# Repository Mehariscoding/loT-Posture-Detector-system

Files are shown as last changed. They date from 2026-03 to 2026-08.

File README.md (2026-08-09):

# IoT Posture Detector System

A closed-loop wearable posture monitoring and correction system designed for long-duration occupational use. The system uses dual IMU sensors to track spinal alignment in real time, delivers haptic feedback to correct slouching behaviour, logs session data to an SD card, and streams live metrics to a web-based dashboard over Bluetooth.

Built and tested as part of an ongoing research effort targeting occupational driver ergonomics.

---

## Repository Structure

```
README.md
CHANGELOG.md
V1/
├── Software/        # Arduino firmware and web dashboard
├── Hardware/        # STL files and wiring schematics
├── Data/            # Session logs and science fair dataset
└── Presentables/    # Judge summary and presentation materials
V2/
├── posture_detector_v2.ino        # ESP32 firmware
├── posture_dashboard_v2_ml.html   # ML dashboard
└── posture_session_v2_ml.csv      # 122-minute stability test data
```

---

## System Overview

Two MPU-6050 IMU sensors are mounted at the upper and lower back. On startup the device runs a stability-based auto-calibration routine that collects 200 samples, identifies the most stable 50-sample window, removes outliers, and computes a median baseline, ensuring the reference posture is not corrupted by movement during initialization.

During monitoring, live sensor readings are continuously compared against the calibrated baseline. If either sensor detects more than 15 degrees of deviation for over 2.5 seconds, the vibration motor triggers a haptic correction alert. Every reading is logged to CSV on an SD card and simultaneously streamed over Bluetooth to a live web dashboard.

---

## V1 Hardware

| Part | Quantity |
|---|---|
| Arduino Uno | 1 |
| MPU-6050 IMU sensor | 2 |
| HC-10 Bluetooth module | 1 |
| Micro SD card module | 1 |
| Coin vibration motor | 1 |
| LED | 1 |
| NPN transistor (2N2222) | 1 |
| 1000uF 50V capacitor | 1 |
| 9V battery + holder | 1 |
| Resistors, jumper wires, breadboard | -- |

---

## V2 Hardware

| Part | Quantity |
|---|---|
| ESP32 Huzzah 32 | 1 |
| MPU-6050 IMU sensor | 2 |
| Micro SD card module | 1 |
| LiPo battery 3000mAh 3.7V | 1 |
| TP4056 charging module | 1 |
| MT3608 boost converter | 1 |
| Coin vibration motor | 1 |
| LED | 1 |
| NPN transistor (2N2222) | 1 |
| Slide switch | 1 |
| JST connectors | 3 |
| Resistors, jumper wires, breadboard | -- |

---

## V1 Wiring

| Component | Arduino Pin |
|---|---|
| MPU-6050 upper (0x68) SDA | A4 |
| MPU-6050 upper (0x68) SCL | A5 |
| MPU-6050 lower (0x69) SDA | A4 (shared) |
| MPU-6050 lower (0x69) SCL | A5 (shared) |
| MPU-6050 lower AD0 | 3.3V |
| HC-10 TXD | Pin 8 |
| HC-10 RXD | Pin 9 |
| SD card CS | Pin 5 |
| LED | Pin 7 |
| Motor (via transistor) | Pin 6 |
| Battery positive | VIN |
| Battery negative | GND |

---

## V2 Wiring

| Component | ESP32 Pin |
|---|---|
| MPU-6050 upper (0x68) SDA | GPIO 23 |
| MPU-6050 upper (0x68) SCL | GPIO 22 |
| MPU-6050 lower (0x69) SDA | GPIO 23 (shared) |
| MPU-6050 lower (0x69) SCL | GPIO 22 (shared) |
| MPU-6050 lower AD0 | 3.3V |
| SD card MOSI | GPIO 18 |
| SD card MISO | GPIO 19 |
| SD card SCK | GPIO 5 |
| SD card CS | GPIO 21 |
| LED | GPIO 12 |
| Motor (via transistor) | GPIO 14 |
| LiPo positive | TP4056 BAT+ |
| TP4056 OUT+ | MT3608 IN+ |
| MT3608 OUT+ | ESP32 VIN |

---

## Libraries

**V1:**
- MPU6050 by Electronic Cats
- SD (built in)
- SoftwareSerial (built in)
- Wire (built in)

**V2:**
- MPU6050 by Electronic Cats
- SD (built in)
- Wire (built in)
- BLEDevice (built in ESP32 core)

---

## Setup

**V1:**
1. Open V1/Software/Posture_Detector.ino in Arduino IDE
2. Install required libraries
3. Select Arduino Uno under Tools, Board
4. Select correct port under Tools, Port
5. Click Upload

**V2:**
1. Open V2/posture_detector_v2.ino in Arduino IDE
2. Install ESP32 board package by Espressif Systems
3. Select Adafruit ESP32 Feather under Tools, Board
4. Select correct port under Tools, Port
5. Click Upload

---

## Usage

1. Power on the device
2. Sit or stand in your natural upright posture
3. Hold still, calibration runs automatically and confirms with a buzz
4. Device monitors continuously and vibrates to correct slouching

---

## Dashboard

**V1:** Open V1/Software/posture_dashboard.html in Chrome.
1. Click Connect to HC-10
2. Select device from Bluetooth scan list
3. Live pitch, roll, status, and score stream in real time

**V2:** Open V2/posture_dashboard_v2_ml.html in Chrome.
1. Click Connect
2. Select PostureDetector_V2 from Bluetooth scan list
3. Live ML inference streams in real time
4. Multi-class classifier, predictive deterioration model, and anomaly detection run in browser

---

## Data Format

SD card logs to posture.csv:

```
Time(ms), PitchU, RollU, PitchL, RollL, Status, Score(%)
```

BLE stream format:

```
U:0.3/0.0 L:0.2/0.1 GOOD 100%
```

---

## 3D Printed Enclosure

**V1:** STL files in V1/Hardware/. Printed in PLA on a Bambu Lab P1S.
- Main case: 150mm x 100mm x 40mm
- Sensor case: 40mm x 45mm x 20mm
- Fastened with M3 thumb screws

**V2:** Redesigned dual elastic band system with TPU cable sleeve. PCB enclosure in development.

---

## Known Limitations (V1)

- Bluetooth connection drops after approximately 20-30 minutes due to power instability on the HC-10 module
- 9V battery provides inconsistent voltage under motor load
- Single-snapshot calibration vulnerable to initialization error if user moves during startup

All of these are resolved in V2.

---

## Stability Test (V2)

- 13,874 readings over 122 continuous minutes
- Zero Bluetooth dropouts
- Max gap between readings: 660ms (expected: 500ms)
- Confirms ESP32 native BLE fully resolves V1 dropout issue

---

## Roadmap

| Version | Status | Key upgrades |
|---|---|---|
| V1 | Complete | Arduino, HC-10, breadboard prototype |
| V2 | Prototype Complete, PCB In Development | ESP32, native BLE, robust calibration, ML dashboard, LiPo power |

---

## Author

Mehar -- Grade 10, Peel Region, Ontario
[GitHub](https://github.com/Mehariscoding)

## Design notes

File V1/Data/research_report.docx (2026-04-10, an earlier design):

IoT Wearable Posture Correction System

Using Dual-Axis IMU Sensors and Real-Time Haptic Feedback

A Research Report Submitted to the Peel Region Science Fair 2025

Mehar

Grade 10, Intermediate Division

Peel Region, Ontario

April 2025

Abstract

Back pain is one of the most widespread health problems in Canada and poor seated posture is a major cause of it. This report presents the design, construction, and testing of a custom-built wearable IoT device that monitors spinal posture in real time using two MPU-6050 inertial measurement unit sensors and delivers vibration alerts when bad posture is detected. The main research question is whether real-time haptic feedback from the device actually causes posture to improve, or whether posture would improve on its own just from wearing the device over time.

Eight 30-minute sessions of data were collected. Sessions 1 through 4 were run with haptic feedback active and sessions 5 through 8 were run with the vibration motor disabled in firmware. Results showed that sessions with feedback averaged 86.3% good posture compared to just 5.3% without feedback. That is a 16-fold difference. The hypothesis was fully supported. The vibration feedback is the main cause of posture improvement, not habit or awareness from wearing the device alone.

Table of Contents

1. Introduction 4

2. Background and Literature Review 5

3. Hypothesis 6

4. Materials and Methods 6

5. Results 9

6. Discussion 11

7. Conclusion 13

8. Future Work 13

9. References 15

1. Introduction

Back pain is one of the most common health problems in Canada. A population-based study found that 83.8% of Canadians will experience back pain in their lifetime, and 34.2% experience it in any given week (Gross et al., 2006). The Canadian Chiropractic Association reports that nearly 45% of Canadians have activity limitations because of chronic back pain, and it is the second-leading driver of short and long-term disability claims in Canada in the occupational context (CCA, 2023). A significant driver of this problem is poor seated posture, especially for students and office workers who sit for several hours per day without any feedback about their spinal alignment.

Current solutions to poor posture are mostly passive. Ergonomic chairs and lumbar supports help but do not correct posture in real time. Commercial wearable devices like the Upright Go 2 exist but use a single sensor on the upper back and cost over $100 USD. No affordable device monitors both the upper and lower back independently and provides live data logging that researchers or clinicians can access. This project addresses that gap by designing and testing a custom-built dual-sensor wearable IoT device from scratch using an Arduino microcontroller, dual MPU-6050 IMU sensors, a vibration motor, and a Bluetooth Low Energy module connected to a real-time web dashboard.

The core research question is: does real-time haptic feedback from a wearable IoT device significantly improve seated posture quality, and is that feedback the actual cause of improvement rather than just wearing the device over time? To answer this, an experimental design was used with four sessions under each condition, with and without the vibration feedback enabled, keeping all other variables constant.

2. Background and Literature Review

2.1 The Problem With Seated Posture

When a person sits for extended periods, the natural tendency is to drift into a forward head position, rounded shoulders, and a flexed lumbar spine. This is sometimes called a slouch posture or C-curve posture. Over time this loading pattern increases stress on the intervertebral discs, compresses posterior spinal structures, and strains the muscles of the thoracic and lumbar regions. The result is chronic back pain that worsens the longer the habit goes uncorrected.

The spine has three natural curves that distribute body weight optimally: cervical lordosis at the neck, thoracic kyphosis at the upper back, and lumbar lordosis at the lower back. A neutral spine maintains all three curves simultaneously. Researchers using IMU sensors placed at thoracic and lumbar vertebral levels define neutral spine as the position where the head and upper trunk are aligned over the rest of the spine, typically captured during a brief upright standing or sitting trial before measurement begins (Carbonaro et al., 2021). This is the anatomical target this device attempts to monitor.

2.2 Haptic Feedback for Posture Correction

Haptic feedback, meaning vibration-based alerts delivered directly to the body, is the most effective and least disruptive method for real-time posture correction. It does not require the user to look at a screen and does not disturb other people nearby the way an auditory alert would. Research has confirmed this across multiple populations (Encyclopedia MDPI, 2024).

The most directly relevant published study is Ferrone et al. (2021), published in MDPI Sensors. The study tested a wearable haptic feedback device using dual IMU sensors on nurses performing common work tasks. The device was tested across three sessions: a baseline session with no feedback, a training session with feedback active, and a validation session with feedback removed. Results showed posture improvement of over 40% for pitch and roll axes comparing the baseline to the training session, and over 50% improvement comparing the baseline to the post-training validation session. Critically, the improvement persisted even after the feedback was removed in session three, suggesting that haptic feedback not only prompts correction in the moment but conditions longer-term postural behaviour. This study used the same sensor type and methodology as this project and directly motivated its design.

2.3 The Calibration Problem

One of the most important challenges in wearable posture devices is ensuring that calibration captures actual good posture rather than the user's habitual or bad posture. If the device calibrates while the user is already slouching, the entire 15-degree threshold is measured from that slouch, meaning the device could allow significant real-world deviation from neutral spine before triggering an alert. This is a known limitation in the field. Carbonaro et al. (2021) note that calibration in wearable IMU systems requires the user to hold a verified neutral anatomical position before data collection begins. Without this, the baseline is arbitrary.

In this study, the calibration limitation was partially addressed through verbal instruction before each session reminding the user to sit upright with ears over shoulders and shoulders over hips, and through consistent use of the same chair and desk across all sessions. However, neutral spine was not mechanically verified or confirmed with a reference tool. This is acknowledged as a limitation and future versions of the device will address it using a physiotherapist-verified standing calibration procedure and reference angle offsets based on published thoracic kyphosis norms.

2.4 Existing Commercial Devices

Several commercial posture wearables exist. The Upright Go 2 retails at approximately $100 USD, uses a single sensor on the upper back, delivers haptic feedback via an app, and stores data in the cloud through the app only with no offline logging. The Upright Go S is a cheaper single-sensor version at approximately $60 USD. The Lumo Lift, which is now discontinued, was a single-sensor device worn on the chest. None of these devices use dual sensors to monitor both the thoracic and lumbar spine independently, none provide offline SD card logging for research purposes, and none are open-source. This project addresses all three of those gaps.

3. Hypothesis

If a wearable IoT device delivers real-time vibration feedback when poor posture is detected, then the percentage of time spent in good posture will be significantly higher during sessions with feedback compared to sessions without feedback. This is because the vibration creates an immediate corrective signal that interrupts sustained bad posture, and repeated exposure to that signal across multiple sessions conditions faster correction responses over time.

4. Materials and Methods

4.1 Device Components

The following components were used to build the device:

- Arduino Uno R3 microcontroller (main processing unit)
- 2x MPU-6050 6-axis gyroscope and accelerometer IMU sensors (posture sensing)
- HC-10 Bluetooth Low Energy module (wireless data streaming to dashboard)
- Micro SD card module with 8GB SD card (offline session logging)
- Coin vibration motor, 3V (haptic alert output)
- NPN transistor 2N2222 with 1 kilohm resistor (motor switching circuit)
- Red LED with 220 ohm resistor (visual alert output)
- 1000 microfarad 50V electrolytic capacitor (power stabilization during motor activation spike)
- 9V battery with holder (portable power supply)
- 3D printed PLA enclosure, designed in Tinkercad, printed on Bambu Lab P1S
- Back brace for wearable mounting on the spine

4.2 Sensor Communication: I2C Protocol

Both MPU-6050 sensors communicate with the Arduino over the I2C bus using shared SDA and SCL lines. I2C allows multiple devices to share just two wires: the SDA line carries the data and the SCL line keeps timing in sync. Both MPU-6050 sensors default to I2C address 0x68, which would cause a bus conflict. To resolve this, the AD0 pin on the lower sensor was connected to 3.3V, which changes its address to 0x69. This allows the Arduino to communicate with the upper sensor at 0x68 and the lower sensor at 0x69 independently on the same two wires. The upper sensor was mounted at thoracic spine level between the shoulder blades. The lower sensor was mounted at lumbar spine level at the lower back.

4.3 Calibration Procedure

When the device is powered on, the user has 5 seconds to sit or stand in their best upright posture. During this period the Arduino samples both sensors 100 times at 10-millisecond intervals and calculates the average pitch and roll value at each sensor location. These averages are stored in memory as the personalized baseline for that session. From that point forward, any reading that deviates more than 15 degrees from the baseline at either sensor triggers the alert system.

The 15-degree threshold was chosen based on published research on IMU-based posture detection systems, which commonly use thresholds in the range of 10 to 20 degrees to balance sensitivity with false positive rate. A lower threshold would generate too many false alerts from normal movement. A higher threshold would miss moderate slouching.

4.4 Alert System Logic

The sensors sample posture at 500-millisecond intervals. When a reading exceeds the 15-degree threshold, a counter increments. The vibration motor and LED only activate after 5 consecutive bad readings, which equals 2.5 seconds of sustained bad posture. This delay prevents false alerts from brief intentional movements such as reaching for something. When the threshold is cleared, the counter resets immediately.

For sessions 5 through 8, the motor activation line was commented out in firmware before uploading to the Arduino. This means the LED still activated during bad posture events, providing a visual indicator, but the user could not feel the vibration. This was done to reduce conscious behavioural bias between conditions since most people are less likely to notice an LED indicator on their back than a vibration.

4.5 Web Dashboard

A real-time web dashboard was built in HTML and JavaScript using the Web Bluetooth API. It connects to the HC-10 BLE module through Chrome on a laptop, displays live pitch, roll, posture status, and a running session score, and allows the full session data to be exported as a CSV file. All session data used in this analysis was collected through this dashboard.

4.6 Experimental Design

Eight sessions were conducted over approximately one week. All sessions used the same desk, same chair, and the same activity: seated homework. Sessions lasted approximately 30 minutes each. Sessions 1 through 4 were conducted with haptic feedback fully active. Sessions 5 through 8 were conducted with the vibration motor disabled. The order was not randomized because the research question included whether posture naturally improves over time with repeated use, which required the feedback sessions to come first.

4.7 Variables

Independent variable: Presence or absence of haptic vibration feedback

Dependent variables: Percentage of readings classified as good posture, percentage classified as bad posture, number of discrete bad posture events per session

Controlled variables: Same desk, chair, activity, device placement on back brace, calibration procedure, session duration

Limitations: Single participant self-study, sensor placement may have varied slightly between sessions, calibration posture not mechanically verified as neutral spine, sessions were not randomized

4.8 Ethics

This project was conducted in compliance with Youth Science Canada's Participation of Humans in Research Low Risk policy. The participant is the student researcher. A Low Risk Approval Form was completed and signed by the participant and parent or guardian prior to data collection. An Informed Consent Letter and Permission Form were also signed. All data is identified only by session number with no additional personal identifiers. The research involves no physical risk beyond normal sitting and wearing of the device.

Claude (Anthropic, 2025) was used as an AI development assistant throughout this project, providing support with Arduino code debugging, BLE web dashboard development, and documentation. All hardware construction, physical assembly, soldering, wiring, sensor calibration, data collection, and analysis were performed independently by the student researcher, in accordance with Youth Science Canada's Guidelines for Using Generative AI in STEM Projects.

5. Results

5.1 Overview

Eight sessions totalling approximately 14,000 individual sensor readings were collected across roughly four hours of posture monitoring. Each session lasted between 17 and 36 minutes. The key metric used throughout this analysis is the percentage of readings classified as good posture, since the cumulative score resets on BLE reconnection and is therefore less reliable as a session-level metric.

5.2 Sessions With Haptic Feedback Active (Sessions 1 to 4)

Table 1 summarizes the four feedback sessions.

Table 1: Sessions with haptic feedback active

- Session 1 (29.4 min): Good posture 71.2%, Bad posture 12.7%, Bad events 40. Baseline session.
- Session 2 (33.1 min): Good posture 80.8%, Bad posture 6.0%, Bad events 39. Improvement of 9.6 percentage points from session 1.
- Session 3 (28.4 min): Good posture 96.0%, Bad posture 1.8%, Bad events 7. Strong conditioning effect observed.
- Session 4 (33.0 min): Good posture 97.1%, Bad posture 1.2%, Bad events 5. Peak performance across all sessions.
- Average: Good posture 86.3%, Bad posture 5.4%, Bad events 23 per session.

5.3 Sessions Without Haptic Feedback (Sessions 5 to 8)

Table 2 summarizes the four no-feedback sessions.

Table 2: Sessions without haptic feedback

- Session 5 (17.3 min): Good posture 13.2%, Bad posture 56.9%, Bad events 87. Immediate collapse without feedback.
- Session 6 (32.9 min): Good posture 1.0%, Bad posture 97.9%, Bad events 8. Sustained bad posture throughout entire session.
- Session 7 (30.3 min): Good posture 5.0%, Bad posture 82.8%, Bad events 82. Consistent with session 5 pattern.
- Session 8 (35.5 min): Good posture 2.0%, Bad posture 96.9%, Bad events 10. Sustained bad posture throughout.
- Average: Good posture 5.3%, Bad posture 83.6%, Bad events 47 per session.

5.4 Key Findings

The headline result is a 16-fold difference in average good posture percentage: 86.3% with feedback versus 5.3% without. Bad posture averaged 5.4% with feedback and 83.6% without. The number of discrete bad posture events per session averaged 23 with feedback and 47 without.

A clear progressive improvement was also observed across sessions 1 through 4. Good posture rose from 71.2% in session 1 to 97.1% in session 4. This represents an 87.5% reduction in bad posture events over the four feedback sessions, from 40 events in session 1 down to 5 in session 4.

Session 6 requires a specific note. It recorded only 8 bad posture events despite having 97.9% bad posture readings. This apparent contradiction is explained by the nature of the event counter. The counter increments only when a bad posture episode begins, not for each individual bad reading within an episode. When the participant stayed in bad posture continuously for an extended period rather than cycling in and out, the event count remained low while the percentage of bad readings remained very high. This is actually a stronger indicator of posture collapse than a high event count, because it means the participant was not making any correction attempts throughout most of the session.

6. Discussion

The results strongly support the hypothesis. Every session with haptic feedback produced dramatically higher good posture rates than every session without it. The 16-fold gap in average good posture percentage is large enough to be meaningful even given the limitations of a single-participant study.

The progressive improvement from 71.2% in session 1 to 97.1% in session 4 shows that the device does more than just prompt correction in the moment. It conditions faster and more automatic correction responses across repeated sessions. This is consistent with findings from Ferrone et al. (2021), who found posture improvements of over 50% persisted even after the feedback was removed in their post-training validation session. That post-training effect is analogous to what appears to happen across sessions 3 and 4 in this study, where good posture reached near-perfect levels even though the user was still in early sessions of use.

The no-feedback sessions are the most important part of the experimental design. Sessions 5 through 8 averaged 83.6% bad posture, which is worse than the very first session with feedback. This directly rules out the alternative explanation that posture naturally improves over time just from wearing the device or from general awareness of being monitored. Without the vibration signal, posture collapsed almost completely. The haptic feedback is not one contributing factor among several. It is the primary mechanism driving the result.

The calibration limitation is important to address honestly. If the user was already in a slightly slouched position during calibration, the 15-degree threshold would be measured from that slouch rather than from true neutral spine. This means the device could permit some real-world deviation from ideal posture before alerting. This is a genuine constraint of the current design and affects how confidently absolute posture quality can be claimed. However, it does not undermine the comparison between conditions, because the calibration procedure was identical in all eight sessions. Whatever offset existed was the same in both groups, so the 16-fold difference between conditions remains a valid finding about the effect of the feedback.

The large jump from session 2 (80.8% good) to session 3 (96.0% good) is notably large. This could reflect true conditioning, but it may also reflect a slight difference in calibration posture or sensor placement between sessions 2 and 3 that happened to produce a more favourable baseline threshold. Stricter mechanical controls on sensor placement between sessions would reduce this ambiguity in future research.

7. Conclusion

This project successfully demonstrated that a custom-built wearable IoT posture correction device using dual MPU-6050 IMU sensors and real-time haptic feedback significantly improves seated posture quality. Sessions with feedback averaged 86.3% good posture compared to 5.3% without, a 16-fold improvement. The hypothesis was fully supported. The device provides an affordable, non-invasive, and open-source method for real-time posture correction during sedentary activity.

These findings align with peer-reviewed research on wearable haptic feedback systems using dual IMU sensors (Ferrone et al., 2021) and published evidence on the effectiveness of haptic correction methods (Encyclopedia MDPI, 2024). With over 83% of Canadians experiencing back pain in their lifetime (Gross et al., 2006) and nearly 45% reporting activity limitations from it (CCA, 2023), an affordable wearable device that can be built for under $80 CAD in components could make real-time posture correction accessible to students, office workers, and occupational health populations who currently have no practical way to monitor their alignment during daily activity.

8. Future Work

8.1 Device Improvements

Version 2 of the device will address the main hardware limitations of the current prototype. The breadboard will be replaced with a custom-designed printed circuit board to reduce the size of the device significantly and improve reliability for extended wear. The Arduino Uno will be replaced with an Arduino Nano to reduce both size and weight. A third MPU-6050 sensor will be added at the cervical spine level to monitor forward head position, which is the most common bad posture pattern during desk work and is not captured by the current two-sensor design.

The calibration system will be redesigned. Version 2 will use a standing calibration procedure where the user stands upright for 5 seconds before sitting, which provides a more reliable neutral spine baseline since gravity alignment is consistent in standing (Carbonaro et al., 2021). The web dashboard will display a guided neutral spine diagram and require the user to confirm correct posture before calibration begins. Reference angle offsets based on published thoracic kyphosis norms, which average 20 to 45 degrees in a healthy seated adult, will also be applied to the baseline to further correct for habitual posture bias.

8.2 Research Study

The Version 2 device will be used in a formal multi-participant study recruiting long-haul truck drivers from a local transportation company. Truck drivers are an ideal occupational health population because they sit for 8 to 12 hours per day and have very high rates of chronic back pain. This study will include a proper experimental and control group design, a longitudinal duration of 4 to 6 weeks to assess whether posture improvements persist after the device is removed, and statistical analysis including t-tests and standard deviation calculations to quantify the significance of results. A physiotherapist will verify neutral spine position for each participant before calibration in each session, eliminating the calibration uncertainty present in this preliminary study.

8.3 Machine Learning

The fixed 15-degree threshold is the same for every user regardless of their natural flexibility and range of motion. A person with hypermobility will have a different functional threshold than someone with a stiff thoracic spine. Version 2 will implement a machine learning algorithm that learns each user's movement patterns over the first few sessions and automatically adjusts the alert threshold to their individual biomechanics, making the device genuinely personalized rather than using a population-average cutoff.

9. References

Ferrone, A., Garcia Patino, A., & Menon, C. (2021). Low back pain: Behavior correction by providing haptic feedbacks: A preliminary investigation. Sensors, 21(21), 7158. https://doi.org/10.3390/s21217158

Gross, D.P., Ferrari, R., Russell, A.S., Battie, M.C., Schopflocher, D., Hu, R.W., Waddell, G., & Buchbinder, R. (2006). A population-based survey of back pain beliefs in Canada. Spine, 31(18), 2142-2145. https://pubmed.ncbi.nlm.nih.gov/16915103/

Canadian Chiropractic Association. (2023). The rise of a static workforce and the role HR can play in tackling the MSK burden. https://chiropractic.ca/wp-content/uploads/2023/06/Rise-of-static-workforce-and-the-role-HR-can-play_CCA-Issues-Paper_2023.pdf

Encyclopedia MDPI. (2024). Wearables for monitoring and postural feedback. https://encyclopedia.pub/entry/55691

Carbonaro, N., Mascherini, G., Bartolini, I., Ringressi, M.N., Taddei, A., Tognetti, A., & Vanello, N. (2021). A wearable sensor-based platform for surgeon posture monitoring: A tool to prevent musculoskeletal disorders. International Journal of Environmental Research and Public Health, 18(7), 3734. https://doi.org/10.3390/ijerph18073734

Anthropic. (2025). Claude [Large language model]. https://claude.ai

IoT Wearable Posture Correction System Mehar

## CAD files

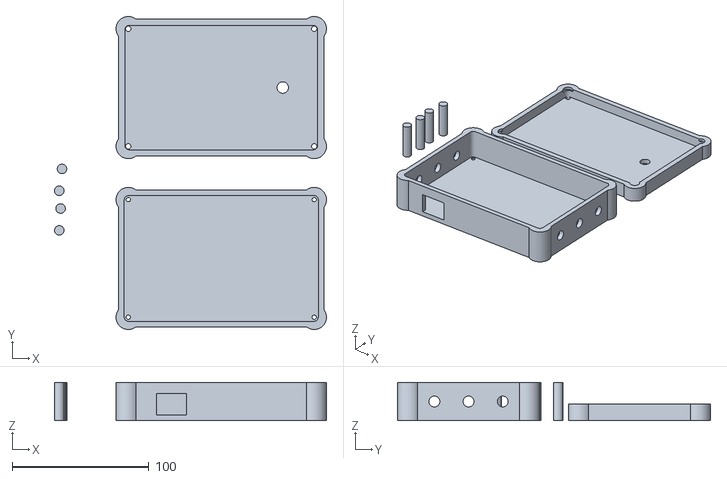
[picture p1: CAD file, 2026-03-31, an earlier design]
V1/Hardware/Main Upper MPU Case.stl
199.0 x 229.0 x 28.0

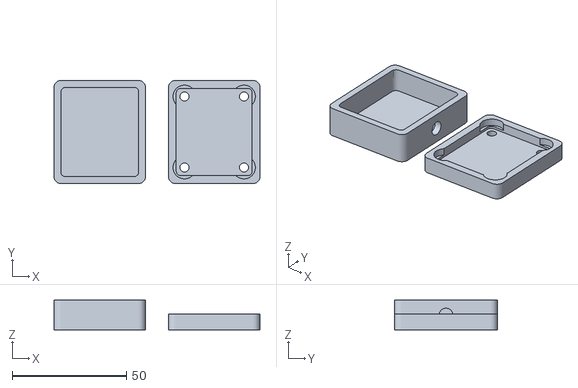
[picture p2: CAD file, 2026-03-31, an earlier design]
V1/Hardware/Lower MPU Case.stl
90.0 x 45.0 x 13.0

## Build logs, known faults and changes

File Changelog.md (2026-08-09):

# Changelog

## V2 — Prototype Complete | PCB In Development

### Hardware
- Replaced Arduino Uno with ESP32 Huzzah 32
- Removed HC-10 Bluetooth module, replaced by ESP32 native BLE
- Replaced 9V battery with LiPo 3000mAh + TP4056 charging circuit
- Added MT3608 boost converter for stable 5V output
- Added slide switch for clean power on/off
- Custom PCB in development (replacing breadboard)
- Redesigned wearable enclosure, dual elastic band system with TPU cable sleeve

### Firmware
- Rewrote calibration system, stability-based window selection, outlier rejection, median baseline
- Migrated Bluetooth from SoftwareSerial HC-10 to ESP32 native BLE (NUS protocol)
- Confirmed 122-minute continuous BLE connection with zero dropouts (V1 dropped at 20-30 min)

### Dashboard
- Full rewrite for Web Bluetooth API
- Added real-time ML inference in browser
- Multi-class posture classifier (Nearest-Centroid, 84.6% accuracy, trained on 15,457 samples)
- Predictive deterioration model (linear regression, 30-second lookahead)
- Anomaly detection (IQR method, asymmetric loading detection)
- Fatigue index (analytics)
- Session intelligence report (analytics)

### Data
- 13,874 readings over 122 minutes, zero Bluetooth dropouts confirmed

---

## V1 — Complete
Built for Peel Region Science Fair 2025.

### Hardware
- Arduino Uno
- HC-10 Bluetooth module
- Dual MPU-6050 IMU sensors
- SD card logging
- 9V battery
- Coin vibration motor + LED alerts
- 3D printed enclosure (PLA)

### Known Limitations
- Bluetooth dropout at 20-30 minutes due to power instability
- Single-snapshot calibration vulnerable to initialization error
- Non-rechargeable power system

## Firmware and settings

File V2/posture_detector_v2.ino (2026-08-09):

#include <Wire.h>
#include <MPU6050.h>
#include <SPI.h>
#include <SD.h>
#include <BLEDevice.h>
#include <BLEServer.h>
#include <BLEUtils.h>
#include <BLE2902.h>

MPU6050 mpuUpper(0x68);
MPU6050 mpuLower(0x69);

// BLE setup
BLEServer* pServer = NULL;
BLECharacteristic* pCharacteristic = NULL;
bool deviceConnected = false;

#define SERVICE_UUID        "6E400001-B5A3-F393-E0A9-E50E24DCCA9E"
#define CHARACTERISTIC_UUID "6E400003-B5A3-F393-E0A9-E50E24DCCA9E"

class MyServerCallbacks : public BLEServerCallbacks {
  void onConnect(BLEServer* pServer) { deviceConnected = true; }
  void onDisconnect(BLEServer* pServer) {
    deviceConnected = false;
    BLEDevice::startAdvertising();
  }
};

float baselinePitchU = 0, baselineRollU = 0;
float baselinePitchL = 0, baselineRollL = 0;
const float THRESHOLD = 15.0;
const int LED_PIN = 12;
const int MOTOR_PIN = 14;
const int CS_PIN = 21;

int totalReadings = 0;
int goodReadings = 0;
int badPostureCount = 0;
const int BAD_POSTURE_DELAY = 5;
bool sdAvailable = false;

// Calibration constants
const int CAL_SAMPLES = 200;
const int WINDOW_SIZE = 50;
const float STABILITY_THRESHOLD = 2.0;

struct SensorReading {
  float pitchU, rollU, pitchL, rollL;
};

float computeVariance(float* arr, int n) {
  float sum = 0;
  for (int i = 0; i < n; i++) sum += arr[i];
  float mean = sum / n;
  float var = 0;
  for (int i = 0; i < n; i++) var += (arr[i] - mean) * (arr[i] - mean);
  return var / n;
}

float computeMedian(float* arr, int n) {
  float sorted[n];
  for (int i = 0; i < n; i++) sorted[i] = arr[i];
  for (int i = 1; i < n; i++) {
    float key = sorted[i];
    int j = i - 1;
    while (j >= 0 && sorted[j] > key) {
      sorted[j + 1] = sorted[j];
      j--;
    }
    sorted[j + 1] = key;
  }
  return (n % 2 == 0) ? (sorted[n/2 - 1] + sorted[n/2]) / 2.0 : sorted[n/2];
}

void filterOutliers(float* arr, int n) {
  float sum = 0;
  for (int i = 0; i < n; i++) sum += arr[i];
  float mean = sum / n;
  float var = 0;
  for (int i = 0; i < n; i++) var += (arr[i] - mean) * (arr[i] - mean);
  float stddev = sqrt(var / n);
  for (int i = 0; i < n; i++) {
    if (abs(arr[i] - mean) > 2.0 * stddev) arr[i] = mean;
  }
}

void sendBLE(String message) {
  if (deviceConnected) {
    pCharacteristic->setValue(message.c_str());
    pCharacteristic->notify();
  }
}

void calibrate() {
  bool calibrated = false;

  while (!calibrated) {
    Serial.println("Calibrating - hold still...");
    sendBLE("Calibrating - hold still...");

    SensorReading buffer[CAL_SAMPLES];

    for (int i = 0; i < CAL_SAMPLES; i++) {
      int16_t ax, ay, az, gx, gy, gz;

      mpuUpper.getMotion6(&ax, &ay, &az, &gx, &gy, &gz);
      buffer[i].pitchU = atan2((float)ay, (float)az) * 180.0 / PI;
      buffer[i].rollU  = atan2((float)ax, (float)az) * 180.0 / PI;

      mpuLower.getMotion6(&ax, &ay, &az, &gx, &gy, &gz);
      buffer[i].pitchL = atan2((float)ay, (float)az) * 180.0 / PI;
      buffer[i].rollL  = atan2((float)ax, (float)az) * 180.0 / PI;

      delay(10);
    }

    int bestWindow = 0;
    float bestScore = 999999;

    for (int w = 0; w <= CAL_SAMPLES - WINDOW_SIZE; w++) {
      float pu[WINDOW_SIZE], ru[WINDOW_SIZE];
      float pl[WINDOW_SIZE], rl[WINDOW_SIZE];

      for (int i = 0; i < WINDOW_SIZE; i++) {
        pu[i] = buffer[w + i].pitchU;
        ru[i] = buffer[w + i].rollU;
        pl[i] = buffer[w + i].pitchL;
        rl[i] = buffer[w + i].rollL;
      }

      float score = computeVariance(pu, WINDOW_SIZE)
                  + computeVariance(ru, WINDOW_SIZE)
                  + computeVariance(pl, WINDOW_SIZE)
                  + computeVariance(rl, WINDOW_SIZE);

      if (score < bestScore) {
        bestScore = score;
        bestWindow = w;
      }
    }

    if (bestScore > STABILITY_THRESHOLD) {
      Serial.println("Too much movement - recalibrating...");
      sendBLE("Too much movement - recalibrating...");
      delay(2000);
      continue;
    }

    float pu[WINDOW_SIZE], ru[WINDOW_SIZE];
    float pl[WINDOW_SIZE], rl[WINDOW_SIZE];

    for (int i = 0; i < WINDOW_SIZE; i++) {
      pu[i] = buffer[bestWindow + i].pitchU;
      ru[i] = buffer[bestWindow + i].rollU;
      pl[i] = buffer[bestWindow + i].pitchL;
      rl[i] = buffer[bestWindow + i].rollL;
    }

    filterOutliers(pu, WINDOW_SIZE);
    filterOutliers(ru, WINDOW_SIZE);
    filterOutliers(pl, WINDOW_SIZE);
    filterOutliers(rl, WINDOW_SIZE);

    baselinePitchU = computeMedian(pu, WINDOW_SIZE);
    baselineRollU  = computeMedian(ru, WINDOW_SIZE);
    baselinePitchL = computeMedian(pl, WINDOW_SIZE);
    baselineRollL  = computeMedian(rl, WINDOW_SIZE);

    calibrated = true;

    float confidence = 1.0 / (1.0 + bestScore);
    Serial.print("Calibrated! Confidence: ");
    Serial.println(confidence, 4);
    sendBLE("Calibrated! Confidence: " + String(confidence, 4));

    digitalWrite(LED_PIN, HIGH);
    digitalWrite(MOTOR_PIN, HIGH);
    delay(200);
    digitalWrite(LED_PIN, LOW);
    digitalWrite(MOTOR_PIN, LOW);
  }
}

void setup() {
  Serial.begin(115200);
  Wire.begin(23, 22);
  pinMode(LED_PIN, OUTPUT);
  pinMode(MOTOR_PIN, OUTPUT);

  // BLE init
  BLEDevice::init("PostureDetector_V2");
  pServer = BLEDevice::createServer();
  pServer->setCallbacks(new MyServerCallbacks());
  BLEService* pService = pServer->createService(SERVICE_UUID);
  pCharacteristic = pService->createCharacteristic(
    CHARACTERISTIC_UUID,
    BLECharacteristic::PROPERTY_NOTIFY
  );
  pCharacteristic->addDescriptor(new BLE2902());
  pService->start();
  BLEDevice::startAdvertising();
  Serial.println("BLE started - PostureDetector_V2");

  mpuUpper.initialize();
  mpuLower.initialize();

  if (!mpuUpper.testConnection()) {
    Serial.println("Upper MPU failed!");
    while (1);
  }
  if (!mpuLower.testConnection()) {
    Serial.println("Lower MPU failed!");
    while (1);
  }

  SPI.begin(5, 19, 18, 21);
  sdAvailable = SD.begin(CS_PIN);
  if (sdAvailable) {
    Serial.println("SD ready!");
    File dataFile = SD.open("/posture.csv", FILE_WRITE);
    if (dataFile) {
      dataFile.println("Time(ms),PitchU,RollU,PitchL,RollL,Status,Score(%)");
      dataFile.close();
    }
  } else {
    Serial.println("SD failed - continuing without it!");
  }

  Serial.println("Stand straight! Auto calibrating in 5 seconds...");
  sendBLE("Stand straight! Auto calibrating in 5 seconds...");
  delay(5000);
  calibrate();
}

void loop() {
  int16_t ax, ay, az, gx, gy, gz;

  mpuUpper.getMotion6(&ax, &ay, &az, &gx, &gy, &gz);
  float pitchU = atan2((float)ay, (float)az) * 180.0 / PI;
  float rollU  = atan2((float)ax, (float)az) * 180.0 / PI;

  mpuLower.getMotion6(&ax, &ay, &az, &gx, &gy, &gz);
  float pitchL = atan2((float)ay, (float)az) * 180.0 / PI;
  float rollL  = atan2((float)ax, (float)az) * 180.0 / PI;

  float pitchDiffU = abs(pitchU - baselinePitchU);
  float rollDiffU  = abs(rollU  - baselineRollU);
  float pitchDiffL = abs(pitchL - baselinePitchL);
  float rollDiffL  = abs(rollL  - baselineRollL);

  totalReadings++;
  String status;

  if (pitchDiffU > THRESHOLD || rollDiffU > THRESHOLD ||
      pitchDiffL > THRESHOLD || rollDiffL > THRESHOLD) {
    badPostureCount++;
    if (badPostureCount >= BAD_POSTURE_DELAY) {
      status = "BAD";
      digitalWrite(LED_PIN, HIGH);
      digitalWrite(MOTOR_PIN, HIGH);
    } else {
      status = "ADJUSTING";
      digitalWrite(LED_PIN, LOW);
      digitalWrite(MOTOR_PIN, LOW);
    }
  } else {
    badPostureCount = 0;
    goodReadings++;
    status = "GOOD";
    digitalWrite(LED_PIN, LOW);
    digitalWrite(MOTOR_PIN, LOW);
  }

  int score = (goodReadings * 100) / totalReadings;

  Serial.print("U-Pitch: "); Serial.print(pitchDiffU, 1);
  Serial.print(" U-Roll: "); Serial.print(rollDiffU, 1);
  Serial.print(" | L-Pitch: "); Serial.print(pitchDiffL, 1);
  Serial.print(" L-Roll: "); Serial.print(rollDiffL, 1);
  Serial.print(" | "); Serial.print(status);
  Serial.print(" | Score: "); Serial.print(score); Serial.println("%");

  String bleMsg = "U:" + String(pitchDiffU, 1) + "/" + String(rollDiffU, 1)
                + " L:" + String(pitchDiffL, 1) + "/" + String(rollDiffL, 1)
                + " " + status + " " + String(score) + "%";
  sendBLE(bleMsg);

  if (sdAvailable) {
    File dataFile = SD.open("/posture.csv", FILE_WRITE);
    if (dataFile) {
      dataFile.print(millis()); dataFile.print(",");
      dataFile.print(pitchDiffU, 1); dataFile.print(",");
      dataFile.print(rollDiffU, 1); dataFile.print(",");
      dataFile.print(pitchDiffL, 1); dataFile.print(",");
      dataFile.print(rollDiffL, 1); dataFile.print(",");
      dataFile.print(status); dataFile.print(",");
      dataFile.println(score);
      dataFile.close();
    }
  }

  delay(500);
}

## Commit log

2026-06-22 Create V1 Readme
    V1 is a wearable Arduino-based posture detector that uses two MPU-6050 sensors on the upper and lower back, detects slouching via angle thresholds, alerts the user with a vibration motor and LED, logs data to an SD card, and streams live data over Bluetooth to a web dashboard.
2026-06-22 Rename Lower MPU Case.stl to V1/Lower MPU Case.stl
    [Lower MPU Case.stl]
2026-06-22 Rename Main Upper MPU Case.stl to V1/Main Upper MPU Case.stl
    [Main Upper MPU Case.stl]
2026-06-22 Rename Raw Data From Session.csv to V1/Raw Data From Session.csv
    [Raw Data From Session.csv]
2026-06-22 Rename V1/Lower MPU Case.stl to V1/Hardware/Lower MPU Case.stl
    [Lower MPU Case.stl]
2026-06-22 Rename V1/Main Upper MPU Case.stl to V1/Hardware/Main Upper MPU Case.stl
    [Main Upper MPU Case.stl]
2026-06-22 Rename V1/Raw Data From Session.csv to V1/Data/Raw Data From Session.csv
    [Raw Data From Session.csv]
2026-08-09 Create V2 Prototype
